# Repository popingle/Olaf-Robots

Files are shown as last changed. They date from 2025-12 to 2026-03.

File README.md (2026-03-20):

# Olaf Robotics

<p align="center">
  
  <br>
  <code>CA : 5fRBazdaTiagUCimxsdhJWZkjYxPFPcUXDG6ngFBpump </code>
</p>

**Olaf Robotics** is an open-source project dedicated to bringing an animated character to life in the physical world. Our goal is to provide a compact, scale-accurate, and highly expressive robotic platform based on the Olaf character, as detailed in the research paper *"Olaf: Bringing an Animated Character to Life in the Physical World"*.

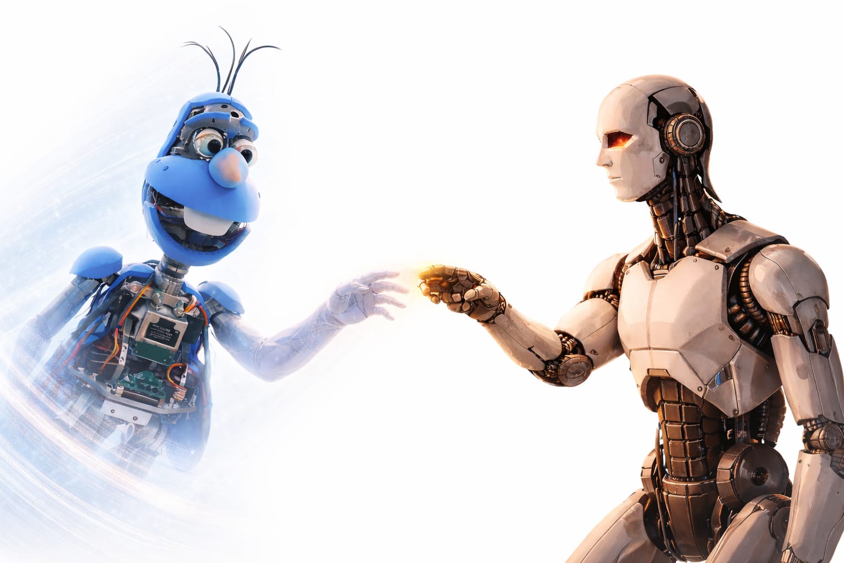
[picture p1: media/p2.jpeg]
Olaf Robotics Banner


---

## 🌐 Multilingual Documentation / 文档 / Dokumentasi

- [English](#overview)
- [Bahasa Indonesia](#ringkasan)
- [中文 (Chinese)](#项目概述)

---

## Overview

Olaf Robotics is a miniaturized, self-walking robotic character designed for agility and believability. This repository contains the mechatronic design (3D printable parts), high-fidelity simulation environments, and reinforcement learning-based control software.

<table align="center">
  <tr>
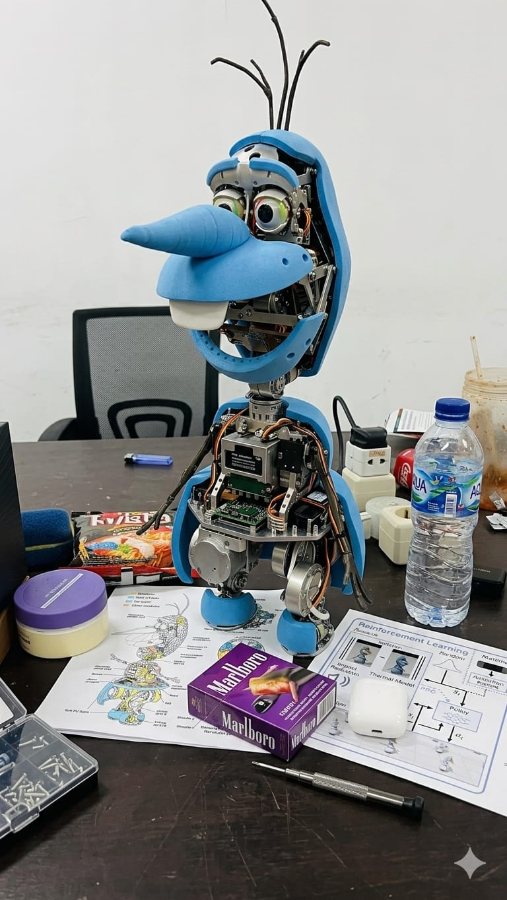
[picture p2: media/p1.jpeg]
Olaf Robot 1
    <td align="center"></td>
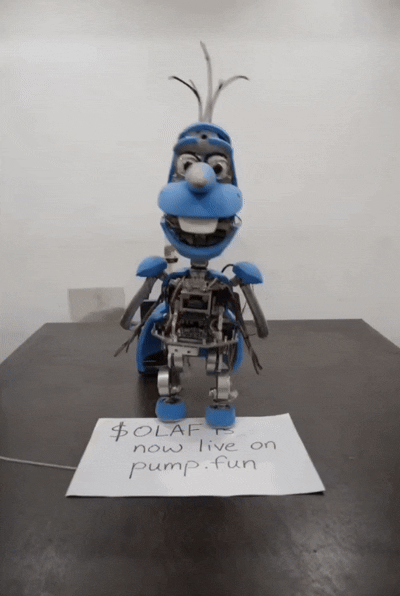
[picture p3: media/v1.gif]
Olaf Animation 1
    <td align="center"></td>
  </tr>
</table>

### 🏗️ Technical Architecture

Our architecture is built on a modular three-layer stack to ensure seamless sim-to-real transition and expressive motion:

Technical Architecture

### 🧠 Split-Brain Architecture Flow
Our dual-processor system separates locomotion from expression to ensure high-frequency motor control and rich social interaction:

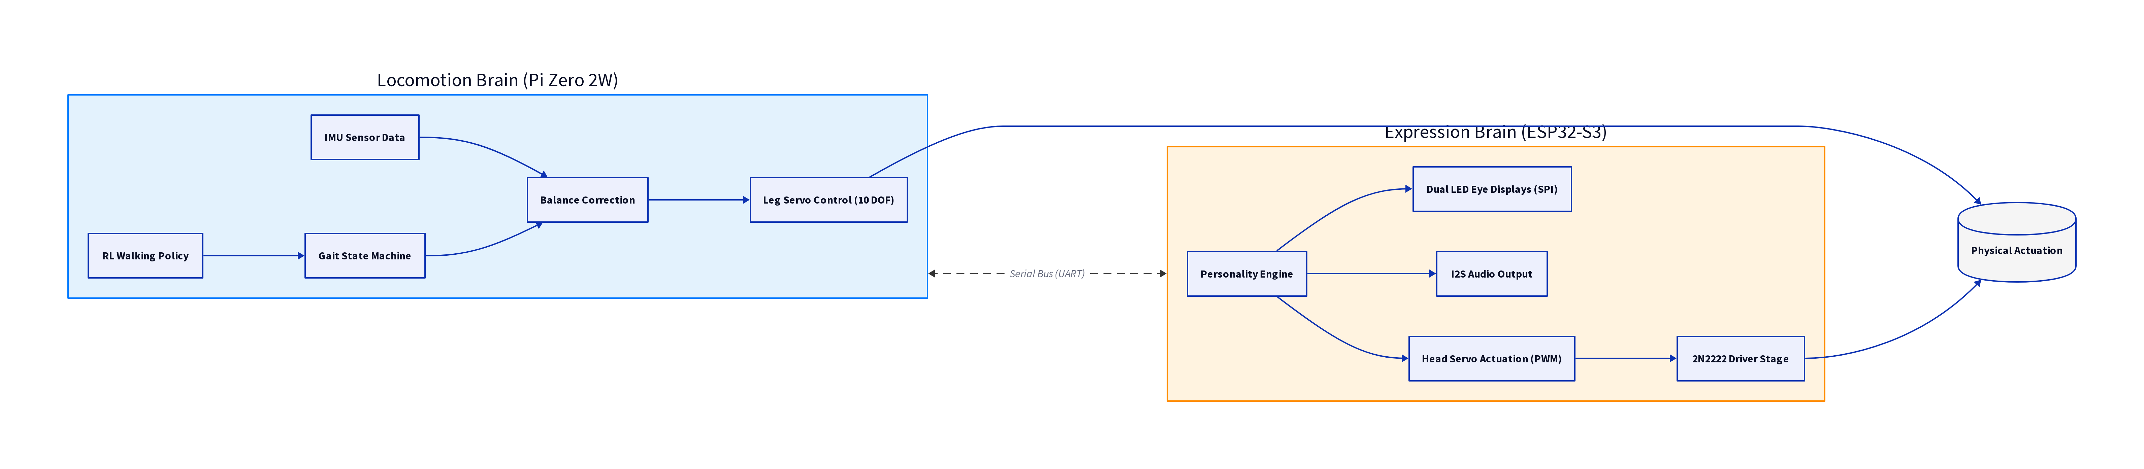
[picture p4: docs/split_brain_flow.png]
Split-Brain Architecture


### ⚙️ Mechatronic Design

The robot's internal structure is meticulously designed to balance weight, power, and expressivity. The shells and skirt are cut away in the diagram below to reveal the complex interior:

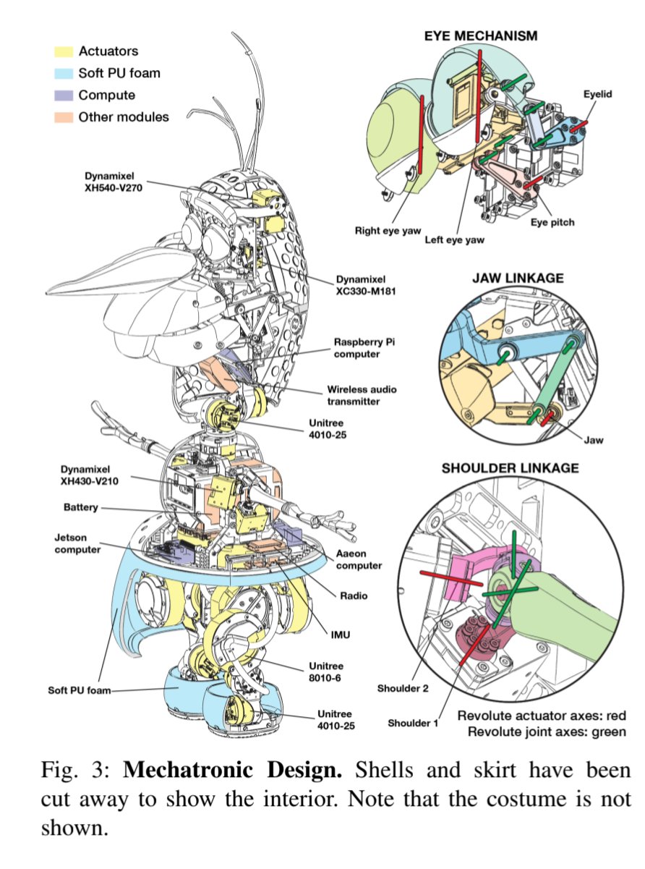
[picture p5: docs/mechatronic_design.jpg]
Mechatronic Design


#### Key Components:
- **Actuators (Yellow)**: High-performance Dynamixel (XH540, XC330, XH430) and Unitree (4010, 8010) motors.
- **Compute (Purple)**: Dual-brain system featuring a **Jetson Computer** for high-level tasks and a **Raspberry Pi** for auxiliary control.
- **Soft PU Foam (Blue)**: Lightweight exterior padding for safety and lifelike feel.
- **Specialized Mechanisms**:
    - **Eye Mechanism**: 3-DoF control for pitch and yaw (left/right) with eyelid movement.
    - **Jaw Linkage**: Precise linkage for expressive mouth movements.
    - **Shoulder Linkage**: Revolute joint axes (red/green) for fluid arm motion.

### 🤖 RL-based Control

We separate the articulated backbone from the show functions. The backbone is controlled via policies conditioned on the high-level control input `gt` and trained using a combination of imitation, overheating, and impact rewards. During training, the control inputs are randomized, whereas at runtime, the Animation Engine generates control inputs from puppeteering commands.

Mechatronic Design and RL-based Control

#### Thermal-aware Policy Performance

Our thermal-aware policy effectively prevents actuator overheating, as demonstrated by the comparison below. The policy significantly reduces joint error and torque when operating under thermal constraints.

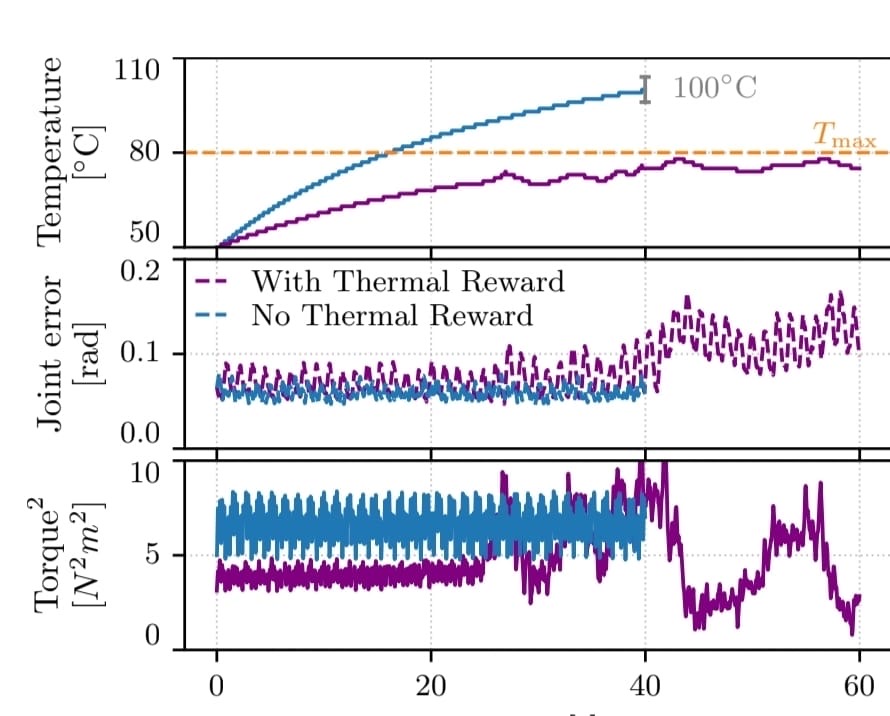
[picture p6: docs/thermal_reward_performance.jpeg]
Thermal Reward Performance


#### Impact Reduction Performance

To ensure quieter and more believable movement, our RL policies incorporate impact noise reduction rewards. The graph below illustrates how this approach minimizes impact forces during locomotion.

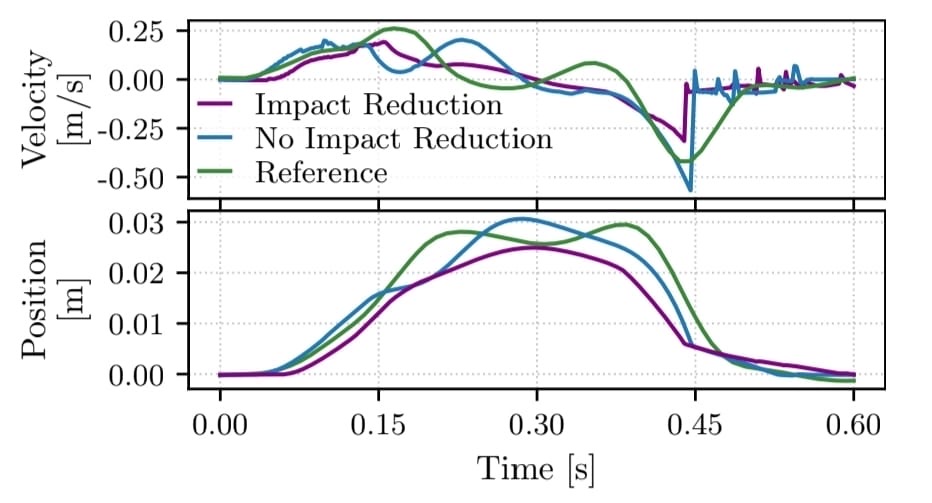
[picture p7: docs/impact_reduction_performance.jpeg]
Impact Reduction Performance


1.  **Mechatronic Design**:
    *   Novel asymmetric **six-degrees-of-freedom (6-DoF)** leg mechanism.
    *   Remotely actuated spherical, planar, and spatial linkages for arms, mouth, and eyes.
    *   Compact design fully hidden beneath a soft foam costume.
2.  **Control Layer (RL & Thermal-aware)**:
    *   **Reinforcement Learning (RL)** policies guided by animation references for lifelike motion.
    *   **Thermal-aware policy** that incorporates actuator temperature to prevent overheating in the slim neck.
    *   Impact noise reduction rewards for quieter, more believable movement.
3.  **Simulation Layer (MuJoCo)**:
    *   High-fidelity physics simulation using **MuJoCo**.
    *   Domain randomization for robust sim-to-real transfer.

### 🛠️ Advanced Features

*   **Polyglot Core Engine**: High-performance components implemented in **C++17**, **C**, and **Rust** for real-time control, low-level communication, and sensor processing.
*   **CI/CD Pipeline**: Automated build and test workflows using GitHub Actions to ensure code stability across multiple languages.
*   **Multilingual Support**: Comprehensive documentation in English, Indonesian, and Chinese.
*   **Modular Design**: Decoupled simulation and hardware layers for rapid prototyping.

---

## Ringkasan

Olaf Robotics adalah proyek robotika open-source yang bertujuan untuk menghidupkan karakter animasi di dunia nyata. Robot ini dirancang dengan fokus pada ekspresi, kelincahan, dan kemiripan dengan karakter aslinya.

### ⚙️ Desain Mekatronik

Struktur internal robot dirancang secara presisi untuk menyeimbangkan berat, daya, dan ekspresivitas. Diagram di bawah menunjukkan komponen interior tanpa kostum:

Mechatronic Design

#### Komponen Utama:
- **Aktuator (Kuning)**: Motor Dynamixel dan Unitree berperforma tinggi.
- **Komputasi (Ungu)**: Sistem dual-brain menggunakan **Jetson Computer** dan **Raspberry Pi**.
- **Mekanisme Khusus**: Kontrol mata 3-DoF, linkage rahang untuk mulut, dan linkage bahu untuk gerakan lengan yang luwes.

### 🤖 Kontrol Berbasis RL

Kami memisahkan *articulated backbone* dari fungsi pertunjukan. *Backbone* dikendalikan melalui kebijakan yang dikondisikan pada input kontrol tingkat tinggi `gt` dan dilatih menggunakan kombinasi imitasi, *overheating*, dan *impact rewards*. Selama pelatihan, input kontrol diacak, sedangkan saat runtime, *Animation Engine* menghasilkan input kontrol dari perintah *puppeteering*.

Mechatronic Design and RL-based Control

#### Performa Kebijakan Sadar Termal

Kebijakan sadar termal kami secara efektif mencegah *overheating* aktuator, seperti yang ditunjukkan oleh perbandingan di bawah ini. Kebijakan ini secara signifikan mengurangi kesalahan sendi dan torsi saat beroperasi di bawah batasan termal.

Thermal Reward Performance

#### Performa Pengurangan Dampak

Untuk memastikan gerakan yang lebih tenang dan meyakinkan, kebijakan RL kami menggabungkan *reward* pengurangan kebisingan dampak. Grafik di bawah ini mengilustrasikan bagaimana pendekatan ini meminimalkan gaya dampak selama lokomosi.

Impact Reduction Performance

1.  **Desain Mekatronik**: Mekanisme kaki 6-DoF asimetris yang inovatif dan linkage untuk lengan, mulut, dan mata.
2.  **Lapisan Kontrol**: Kebijakan Reinforcement Learning (RL) yang dipandu oleh referensi animasi dan kebijakan sadar termal untuk mencegah overheating.
3.  **Lapisan Simulasi**: Simulasi fisika fidelitas tinggi menggunakan MuJoCo.

---

## 项目概述

Olaf Robotics 是一个开源机器人项目，旨在将动画角色带入现实世界。该机器人专注于表现力、灵活性和与原角色的比例一致性。

### ⚙️ 机电设计

机器人的内部结构经过精心设计，以平衡重量、动力和表现力。下图展示了去除外壳后的内部组件：

Mechatronic Design

#### 核心组件：
- **执行器（黄色）**：高性能 Dynamixel 和 Unitree 电机。
- **计算单元（紫色）**：搭载 **Jetson** 和 **Raspberry Pi** 的双大脑系统。
- **专用机构**：3自由度眼睛机构、用于表情的下颌连杆以及用于流畅手臂动作的肩部连杆。

### 🤖 基于RL的控制

我们将关节骨架与表演功能分离。骨架通过以高级控制输入 `gt` 为条件的策略进行控制，并使用模仿、过热和冲击奖励的组合进行训练。在训练期间，控制输入是随机的，而在运行时，动画引擎从操纵命令生成控制输入。

Mechatronic Design and RL-based Control

#### 热感知策略性能

我们的热感知策略有效地防止了执行器过热，如下面的比较所示。该策略在热限制下显著降低了关节误差和扭矩。

Thermal Reward Performance

#### 冲击减少性能

为了确保更安静、更逼真的运动，我们的强化学习策略结合了冲击噪声减少奖励。下图说明了这种方法如何在运动过程中最大限度地减少冲击力。

Impact Reduction Performance

1.  **机电设计**：创新的非对称六自由度 (6-DoF) 腿部机构，以及用于手臂、嘴巴和眼睛的远程驱动连杆。
2.  **控制层**：由动画参考引导的强化学习 (RL) 策略，以及包含执行器温度输入的散热感知策略。
3.  **仿真层**：使用 MuJoCo 进行高保真物理仿真。

---

## Getting Started

### Hardware Assembly
Detailed assembly instructions can be found in the [Assembly Guide](docs/assembly_guide.md).

#### 📋 Bill of Materials (BOM)
The total cost for the Olaf Robot hardware is designed to be accessible. Below is the visual breakdown:

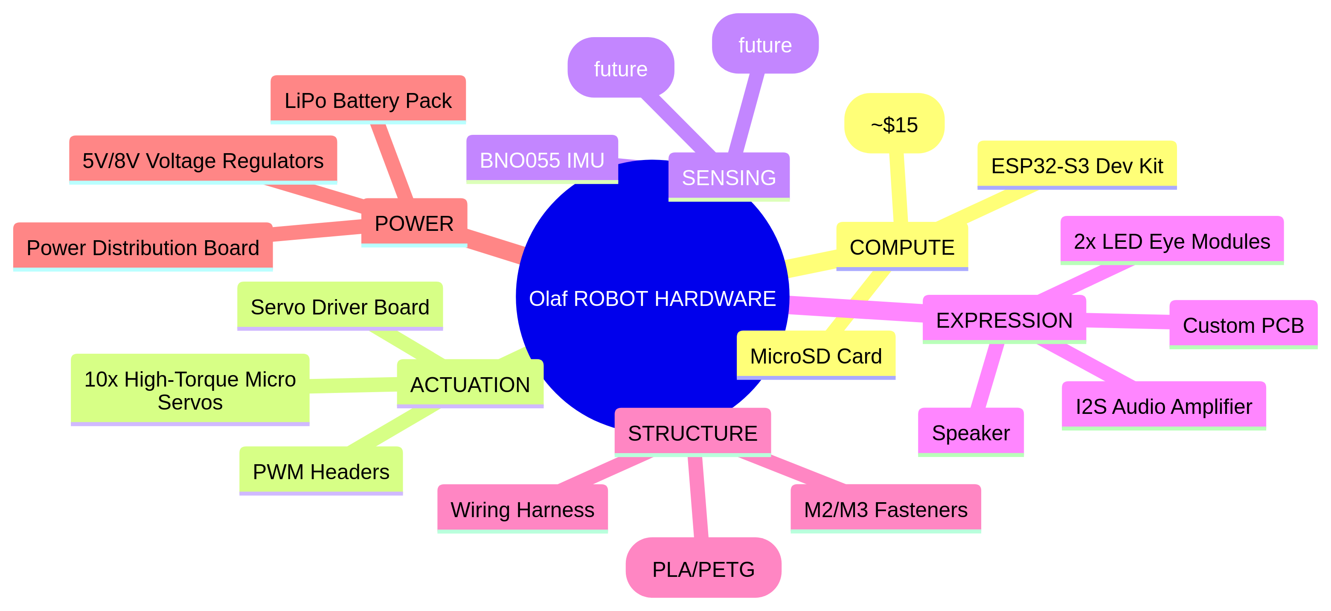
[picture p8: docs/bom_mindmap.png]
Olaf Robotics BOM Mind Map


### Software Installation
To install the core library and dependencies:
```bash
pip install -e .
```

### Simulation
We use MuJoCo for simulation. You can find the robot descriptions and simulation scripts in the `olaf_robot/robots` and `experiments` directories.

## Project Structure
- `print/`: STL files and 3D printing modifications.
- `olaf_robot/`: Core Python package and robot descriptions.
- `docs/`: Documentation and wiring diagrams.
- `experiments/`: Research scripts for RL, motion planning, and real-robot tests.
- `src/`: Polyglot core engine (C++, C, Rust).
- `scripts/`: Automation and deployment scripts.

## License
This project is licensed under the MIT License - see the [LICENSE](LICENSE) file for details.

---
*Bringing an animated character to life in the physical world.*

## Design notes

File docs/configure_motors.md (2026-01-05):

# Configure the motors

> This sould be done independently on each motor *before* builiding the Olaf.
>
> During the process, the motor will move to its zero position. You can then install the horn while trying to align it the best you can like in the photo below. (Don't worry if it's not perfect, we will compensate for that later)

Capture d’écran du 2025-04-25 09-55-34

Clone and install (`pip install -e .`) the runtime repo on the `v2` branch : `https://github.com/olaf-robotics/Olaf_Robots_Runtime`

You can either install it on your own computer or on the raspberry pi for the configuration, as you want. You'll just want a way to power the servos, for example, the battery pack.

Then for each motor, run the following command : 

```bash
python configure_motor.py --id <id>
```

The motors ids are : 

```python
{
    "left_hip_yaw": 20,
    "left_hip_roll": 21,
    "left_hip_pitch": 22,
    "left_knee": 23,
    "left_ankle": 24,
    "neck_pitch": 30,
    "head_pitch": 31,
    "head_yaw": 32,
    "head_roll": 33,
    "right_hip_yaw": 10,
    "right_hip_roll": 11,
    "right_hip_pitch": 12,
    "right_knee": 13,
    "right_ankle": 14,
}
```

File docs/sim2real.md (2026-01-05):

> Not finalized yet

# Training policies that transfer to the real robot (sim2real)

We want to train policies that transfer well to the real robot. This is the sim2real problem. It's a hard problem, especially for us since we are using cheap servomotors that are hard to model and not overly powerful. 

Below, I'll roughly explain the steps we went through to get there, but you won't have to do everything again yourself since we provide the results of each process.

## Make an accurate model of the robot (URDF/MJCF)

### Robot structure

In the [Onhape document](https://cad.onshape.com/documents/64074dfcfa379b37d8a47762/w/3650ab4221e215a4f65eb7fe/e/0505c262d882183a25049d05), we specify the material of each part. But to be more accurate, because we print with infill we override the mass of the parts with the (pretty accurate) estimation of the slicer. 

We use [onshape-to-robot](https://github.com/Rhoban/onshape-to-robot) to export URDF/MJCF descriptions. For MJX, we have to make a lightweight model, see our [config.json](https://github.com/olaf-robotics/Open_Olaf_Playground/blob/main/playground/Olaf_Robots_v2/xmls/config.json). 

This gives us a MJCF (Mujoco format) [description of the robot](https://github.com/olaf-robotics/Open_Olaf_Playground/blob/main/playground/Olaf_Robots_v2/xmls/Olaf_Robots_v2.xml) which describes the masses and moments of inertia of the full robot. 

### Motors

Another very important part of having an accurate model is modeling the motors's behavior. We use [BAM](https://github.com/Rhoban/bam/) for that. You don't have to go through the identification process yourself, we provide the results [here](https://github.com/Rhoban/bam/tree/main/params/feetech_sts3215_7_4V)

It's critical that the simulator simulates the motors accurately, because we will train a policy (a neural network) to output motor positions based on sensory inputs (motors positions/speeds, imu and feet sensors). If the motors behave differently in the simulation than in the real world, the policy won't work, or at worst, produce chaotic movements.

`BAM` allows us to export the main identified parameters to mujoco units (using `bam.to_mujoco`). These values are the ones we set in out mjcf model for the actuators and joints properties. 

- damping
- kp
- frictionloss
- armature
- forcerange

## Training policies 

We use our own [mujoco playground](https://github.com/google-deepmind/mujoco_playground) based framework, [Open Olaf Playground](https://github.com/olaf-robotics/Open_Olaf_Playground)

In the [joystick](https://github.com/olaf-robotics/Open_Olaf_Playground/blob/main/playground/Olaf_Robots_v2/joystick.py) env, you can try to enable/disable different rewards, write your own, play with the weights, noise, randomization etc. 

We obtained good results by implementing the imitation reward described by Disney in their [Olaf paper](https://github.com/olaf-robotics/Open_Olaf_Playground/blob/main/playground/Olaf_Robots_v2/joystick.py). 

To use this reward, we need reference motion. We made [this repo](https://github.com/olaf-robotics/Open_Olaf_reference_motion_generator) to generate such motion using a parametric walk engine. Following the instructions there, you can generate a `polynomial_coefficients.pkl` file which contains the reference motions. There is already such a file in the playground repo under the `data/` directory. 

Once your policy is trained, you can try to run it on the real robot using [this script](https://github.com/olaf-robotics/Olaf_Robots_Runtime/blob/v2/scripts/v2_rl_walk_mujoco.py) in the runtime repo. Make sure you completed all the steps in the [checklist](https://github.com/olaf-robotics/Olaf_Robots_Runtime/blob/v2/checklist.md) before running this.

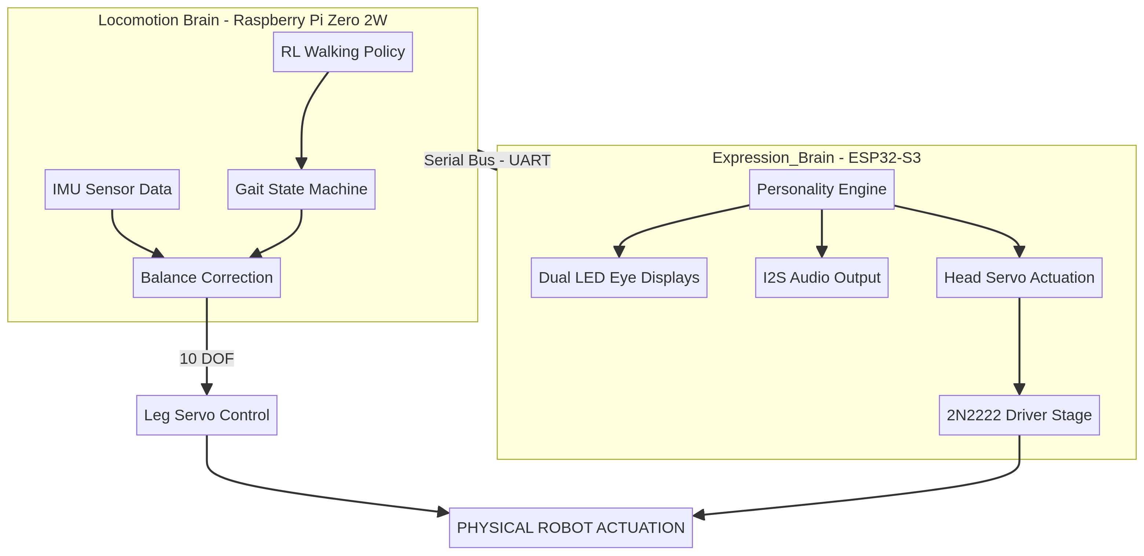
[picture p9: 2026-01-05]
docs/split_brain_architecture.png

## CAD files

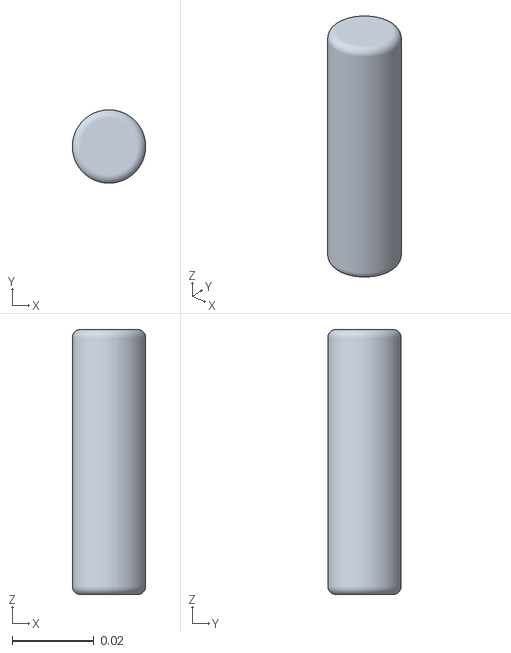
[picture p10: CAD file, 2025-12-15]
olaf_robot/robots/bdx/cell.stl
0.018 x 0.018 x 0.065

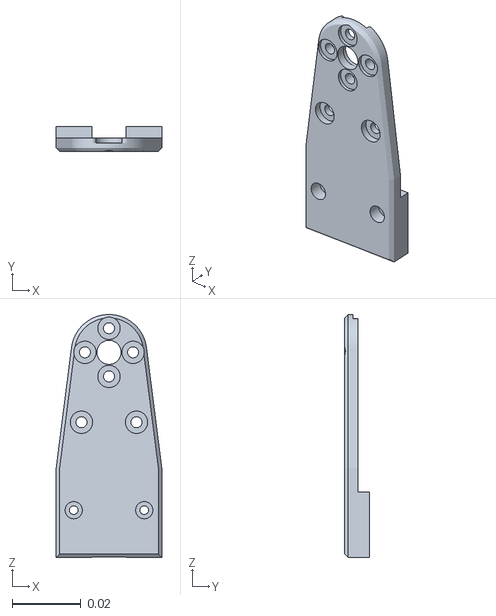
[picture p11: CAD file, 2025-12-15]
olaf_robot/robots/olaf_robots_v2/left_knee_to_ankle_right_sheet.stl
0.0307 x 0.0072 x 0.0706

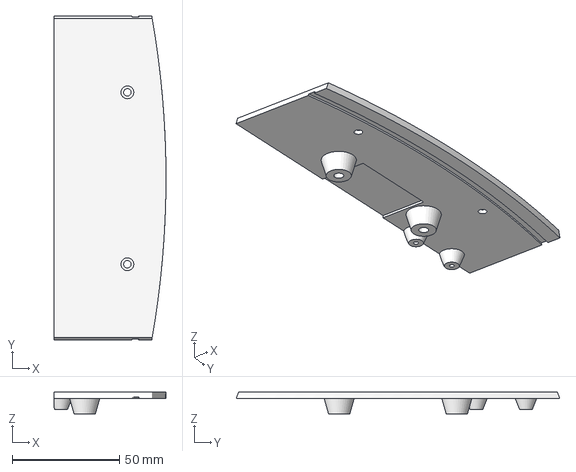
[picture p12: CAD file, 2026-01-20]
print/mods/Justins_Park_Head_Mod/print cut for A1/Front_Top.3mf
52.1 x 150.6 x 10.1 mm

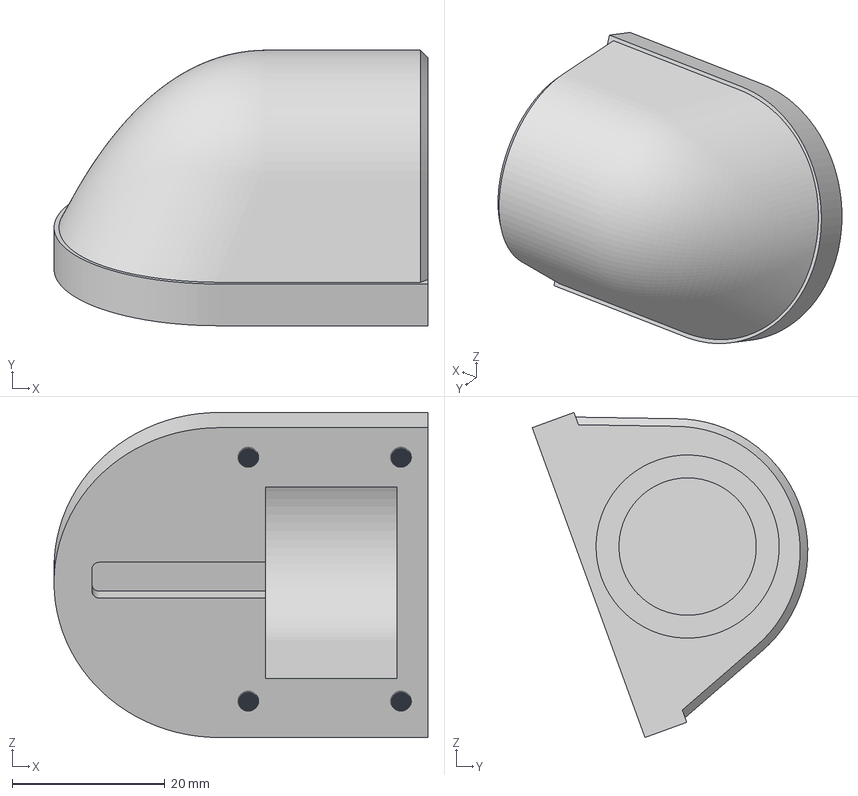
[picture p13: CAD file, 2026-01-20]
print/mods/Justins_Park_Head_Mod/print/FlashlightBody.3mf
49.0 x 36.1 x 42.6 mm

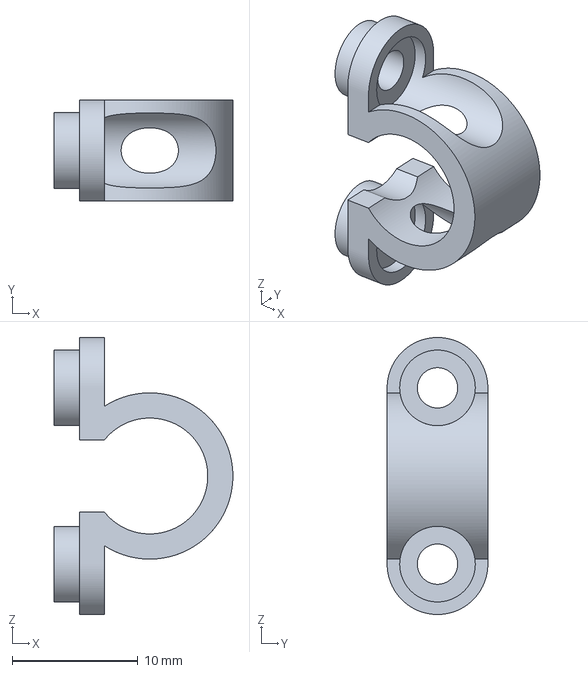
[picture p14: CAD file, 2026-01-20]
print/mods/v2_Jaimes_Mods/Hip Cable Holder.3mf
14.2 x 8.00 x 22.0 mm

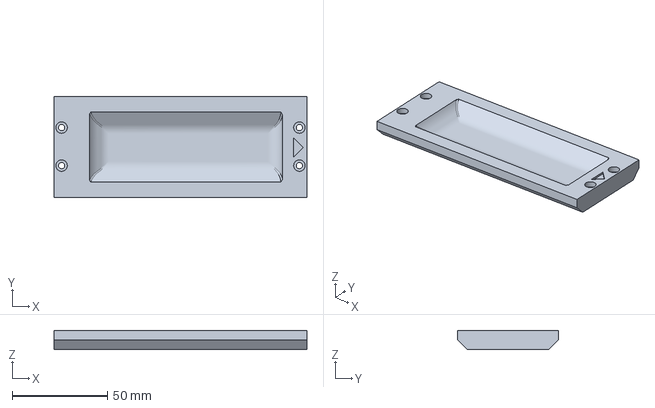
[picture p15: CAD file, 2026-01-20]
print/mods/v2_Jaimes_Mods/stand/Left_foot_pad.3mf
133.0 x 52.8 x 10.1 mm

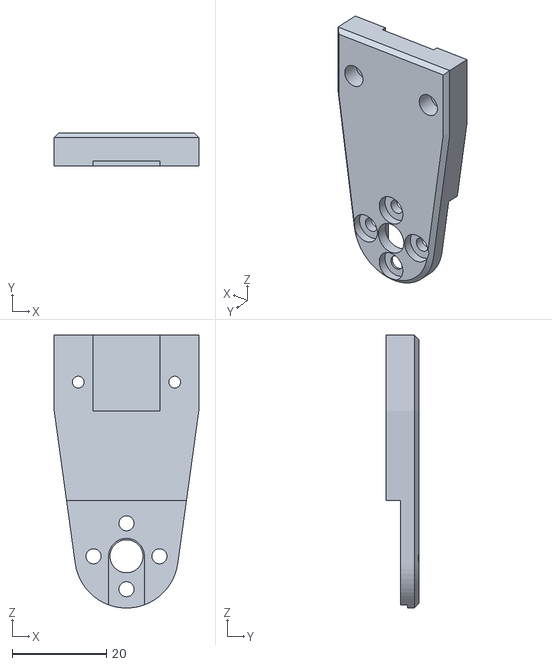
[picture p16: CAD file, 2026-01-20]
print/neck_left_sheet.stl
30.7 x 7.05 x 58.0

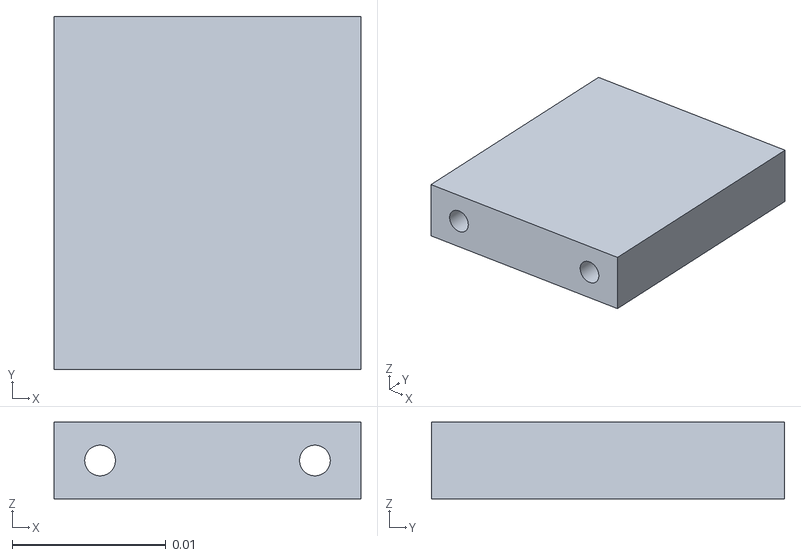
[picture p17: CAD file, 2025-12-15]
olaf_robot/robots/bdx/renfort_leg.stl
0.02 x 0.023 x 0.005

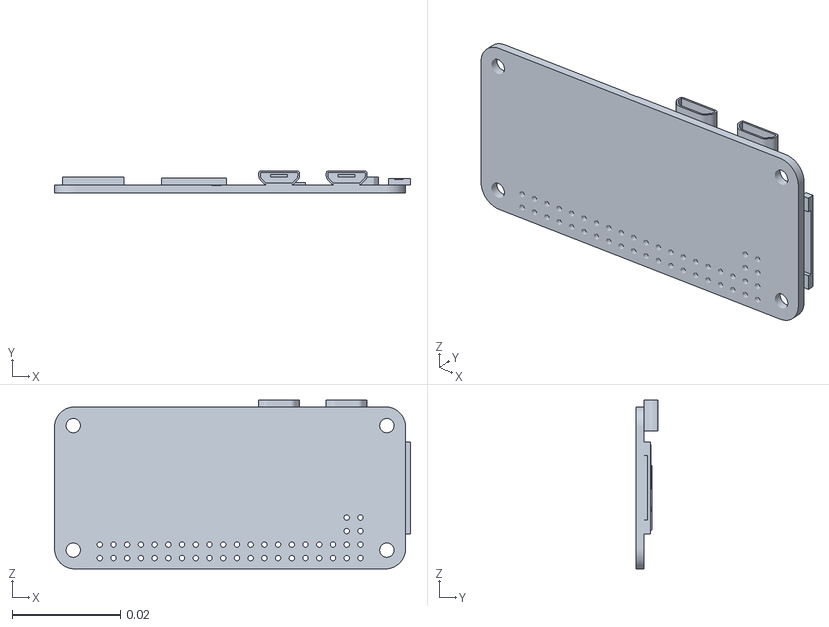
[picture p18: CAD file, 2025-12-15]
olaf_robot/robots/olaf_robots_v2/raspberrypizerow.stl
0.0659 x 0.0041 x 0.0312

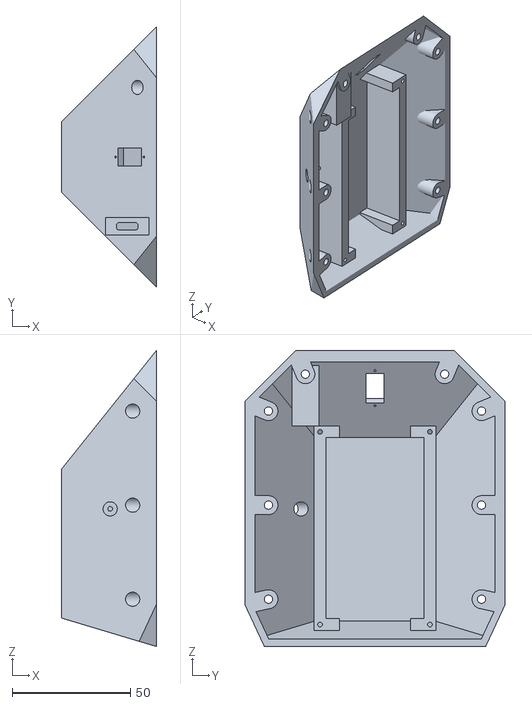
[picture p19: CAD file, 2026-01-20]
print/body_back.stl
40.0 x 110.0 x 125.0

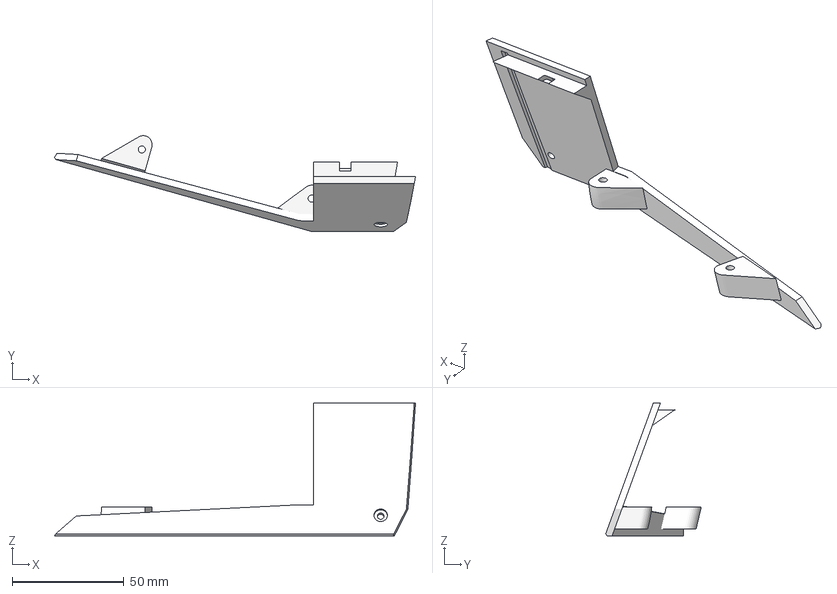
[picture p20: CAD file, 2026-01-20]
print/mods/Justins_Park_Head_Mod/print cut for A1/Front_Right.3mf
161.4 x 42.8 x 59.4 mm

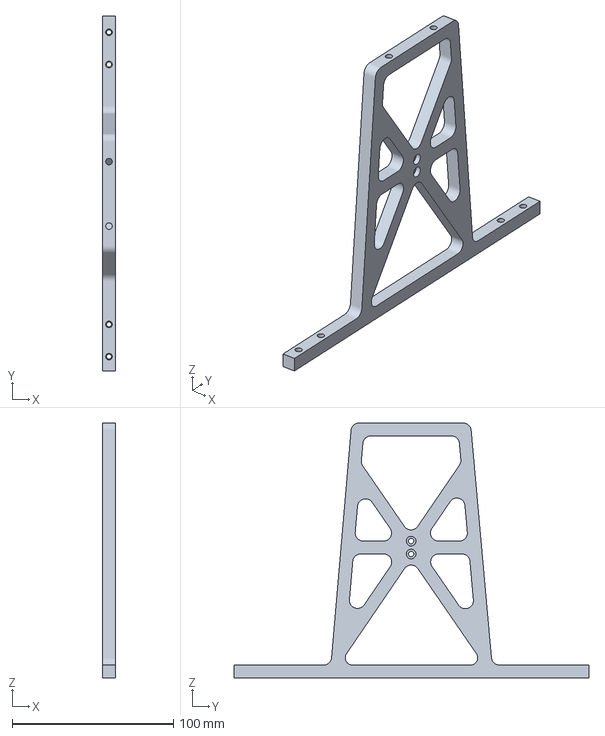
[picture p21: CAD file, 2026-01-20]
print/mods/v2_Jaimes_Mods/stand/stand_front.3mf
8.00 x 220.0 x 158.2 mm

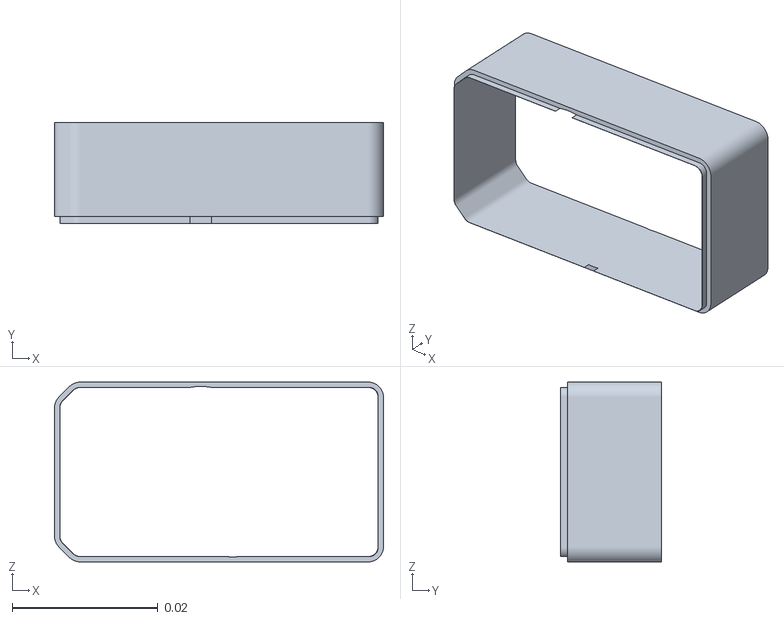
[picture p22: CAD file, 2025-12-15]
olaf_robot/robots/olaf_robots_v2/wj-wk00-0123middlecase_56.stl
0.0452 x 0.0139 x 0.0247

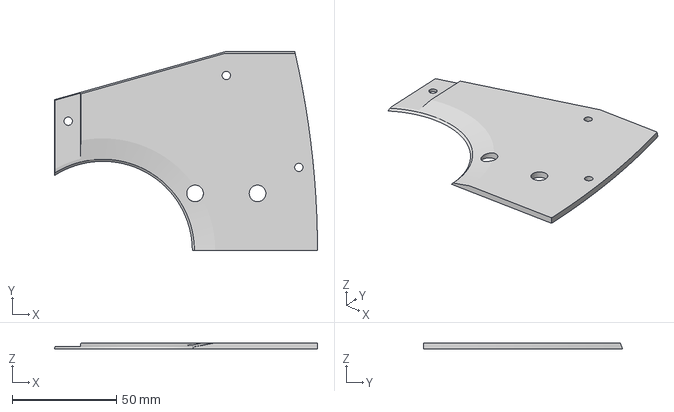
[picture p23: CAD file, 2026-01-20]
print/mods/Justins_Park_Head_Mod/print cut for A1/Base_FrontLeft.3mf
126.3 x 95.7 x 3.00 mm

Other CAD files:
print/mods/Justins_Park_Head_Mod/print/Parklike_Left_Eye.3mf
print/mods/v2_Jaimes_Mods/Bambu_X1C_Project_File.3mf
print/mods/Justins_Park_Head_Mod/print/Parklike_Right_Eye.3mf
print/mods/v2_Jaimes_Mods/stand/Right_foot_pad.3mf
olaf_robot/robots/bdx/39281023.prt.stl
olaf_robot/robots/bdx/antenna.stl
olaf_robot/robots/bdx/antenna_holder_left.stl
olaf_robot/robots/bdx/antenna_holder_right.stl
olaf_robot/robots/bdx/antenna_motor_holder.stl
olaf_robot/robots/bdx/antenna_tip.stl
olaf_robot/robots/bdx/axis_to_axis.stl
olaf_robot/robots/bdx/block_to_axis.stl
olaf_robot/robots/bdx/bms.stl
olaf_robot/robots/bdx/bno055.stl
olaf_robot/robots/bdx/board.stl
olaf_robot/robots/bdx/body_part.stl
olaf_robot/robots/bdx/cage_back.stl
olaf_robot/robots/bdx/cage_bottom.stl
olaf_robot/robots/bdx/cage_bottom_battery_hold.stl
olaf_robot/robots/bdx/cage_top.stl
olaf_robot/robots/bdx/dc15_a01_case_b_dummy.stl
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

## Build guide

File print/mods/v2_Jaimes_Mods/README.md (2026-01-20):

# Jaime's V2 BD‑X Style Body Covers Mod

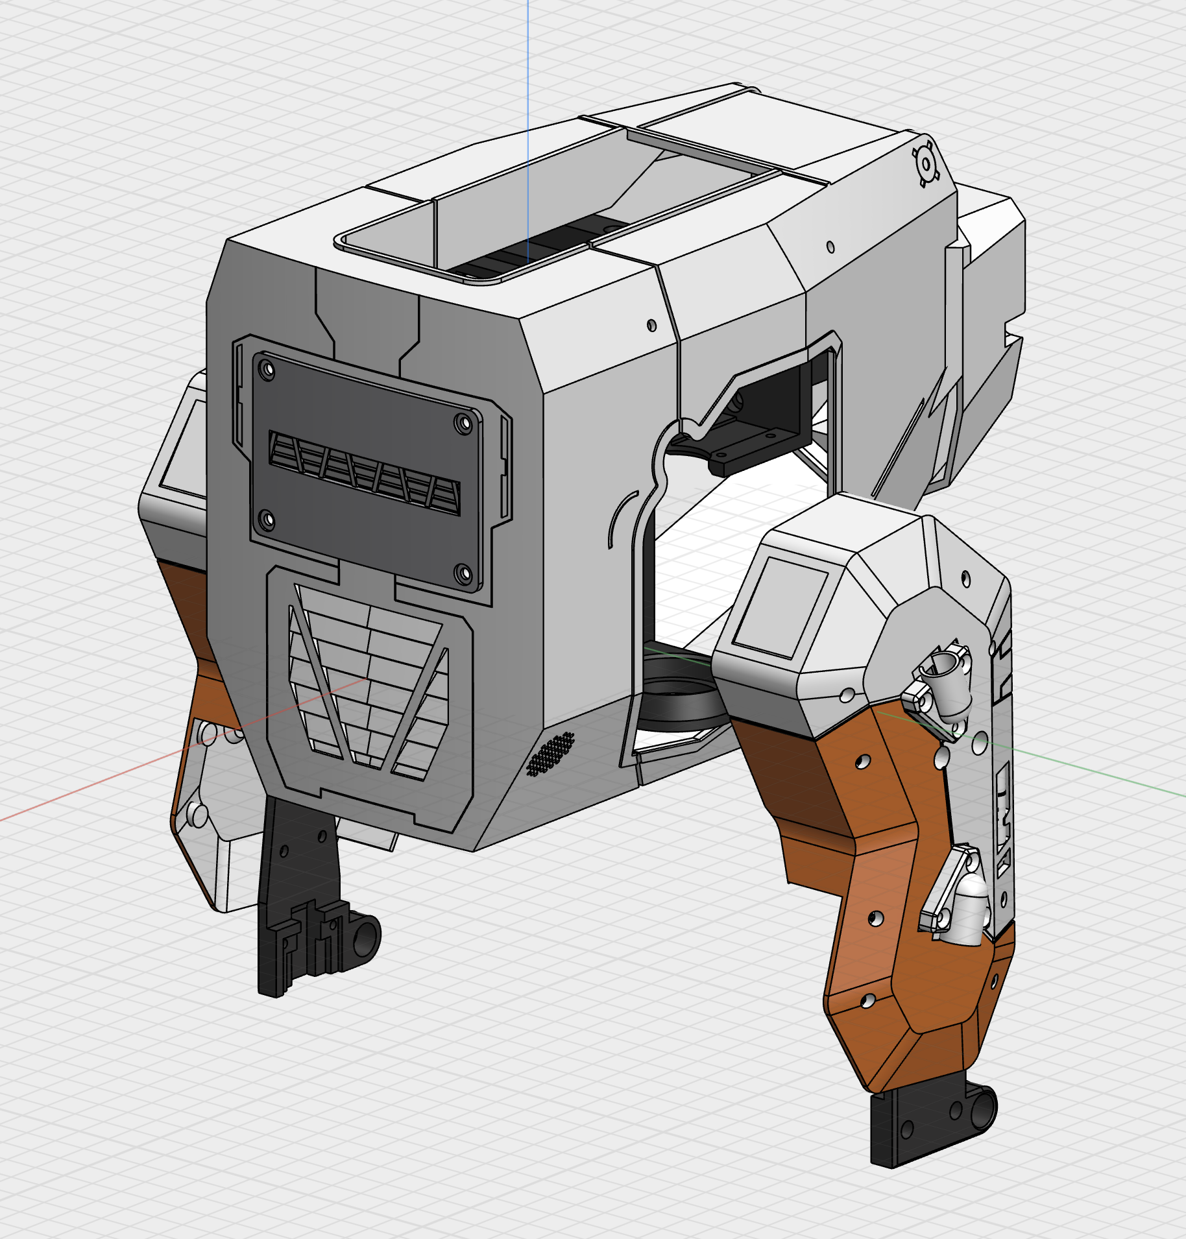
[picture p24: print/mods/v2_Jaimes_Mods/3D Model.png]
3D Model Overview


Author: Jaime Machuca (jmachuca77)

## Purpose
This is an alternative set of v2 body/head cover parts for Olaf Robots intended to more closely match the Disney BD‑X aesthetic and surface "skin" lines.

## Important Note on Balance & RL Policy
These covers shift the overall mass distribution and do not perfectly match the original center of gravity assumptions used when training the current reinforcement learning (RL) locomotion policy. The existing policy still works, but may exhibit slightly reduced stability (e.g. more wobble, occasional recovery steps). Monitor performance; if instability becomes an issue, consider fine‑tuning or retraining with updated inertial parameters.

## Printing Guidance
The file `Bambu_X1C_Project_File.3mf` contains suggested part orientations, plate groupings, and baseline settings optimized for a Bambu Labs X1C printer.

Recommended starting points (adjust to your material):
- Material: PETG or PLA-CF (for durability)
- Layer Height: 0.20 mm (features) / 0.28 mm (large flat shells optional)
- Infill: 15–20% gyroid or cubic
- Walls: 3 perimeters for strength on structural covers
- Supports: Only where unavoidable (check project file flags)
- Adhesion: Skirt or minimal brim for tall narrow pieces

Print Orientation Reference

## Included Parts
Representative filenames (see folder for full list):
- Front/Back/Side body covers (`Front Cover.3mf`, `Back Panel.3mf`, `trunk_*`) 
- Leg covers and cable guides (`Left Leg Cover.3mf`, `Right Leg Cover.3mf`, upper/lower guides) 
- Greebles & panels (`Front Greeble.3mf`, `Front Panel V4.3mf`) 
- Safety / accessory plates (`E-Stop Panel.3mf`, `E-Stop Adapter Plate.3mf`) 
- Assembly helpers (`Hip Cable Holder.3mf`, `Top Body Support.3mf`)

## Usage & Attribution
Feel free to remix or adapt. Please retain attribution to Jaime Machuca (jmachuca77) and reference that this mod targets a closer Disney BD‑X visual style.

## Future Suggestions
- Retrain or fine‑tune RL policy with updated CAD mass properties.

---
If you encounter issues or improved orientations, open a PR or add notes here.

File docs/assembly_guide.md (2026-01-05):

# Assembly guide

> Before assembling the Olaf, you should first [configure your motors](./configure_motors.md)

## Requirements : 

You will need : 
- A soldering iron, and basic electronics tools and skills
- X m3 screws (TODO : add the exact number)
- Some wire
- Loctite Threadlocker blue 243

> General note : Everytime you screw something in the motors metal against metal, you want to use a little loctite threadlocker. This will prevent the screws from coming loose due to the vibrations during the operation of the robot. It adds a little time to to the build, but you'll be glad you took the time ;)
>
> Don't use loctite with the plastic screws

> At any time, you can refer to the CAD here : https://cad.onshape.com/documents/64074dfcfa379b37d8a47762/w/3650ab4221e215a4f65eb7fe/e/0505c262d882183a25049d05

## Steps :

### Assemble the trunk

Place the bearings in `trunk_bottom` like so, and insert M3 inserts in these holes. It's also a good time to insert the 4 M3 inserts in the bottom of this part to mount body parts later on.



Then assamble `trunk_bottom` and `trunk_top`, and screw them together with 2 `M3x10` screws through these holes



Mount the middle motor like so and screw it with the plastic screws that came with the motors : 



Insert `roll_motor_bottom` like this 



### Assemble the feet

Both feet are the same. 

First, assemble `foot_bottom_tpu` with `foot_bottom_pla`. Insert M3 inserts in these holes :



And screw the two parts together with two `M3x6` screws.

Then, insert M3 inserts in these holes in `foot_top` here : 



And assemble everything like so. Make sure the driver side of the motor is on the `foot_top` part side : 

<table>
  <tr>
    <td>  </td>
    <td>  </td>
   </tr> 
</table>

You can add the foot switches like this too :

> You press fit them so that the switch is activated when the foot touches the ground

<table>
  <tr>
    <td>  </td>
    <td>  </td>
   </tr> 
</table>

### Assemble the shins

Insert M3 Inserts in these holes of `leg_spacer` (on both sides. Insert 4 M3 inserts in total) :



Then, first plug the motor cable in the foot's motor, and make it go through the `right_sheet` like so 



Then assemble like below:



### Assemble the thighs 

The thigh is pretty much the same thing, except the `hip_pitch` motor is mounted this way (important for the zero position)



### Assemble the hips

Mount `left_roll_to_pitch` or `right_roll_to_pitch`, here the parts are symmetrical so you have to use the right one.



Mount `roll_motor_top` to the `hip_yaw` servo (screw from the bottom). Don't mount the servo to the trunk yet.



Then mount `hip_roll` like this 



And insert the sub assembly like this 



Screw everything you can (with the plastic screws provided with the servos)

You can now mount the leg like this :



And do the same for the other leg :)

Your Olaf should now look like this 



### Assemble the neck

You know the drill



### Assemble the head mechanism

First, mount `head_pitch_to_yaw` like this 



Then, independently mount `head_yaw_to_roll` and `head_roll_mount` to `head_roll dof`



(You can insert `head_bot_plate` and `body_middle_top` now too to avoid having to disassamble the head later)

Then 



Then 



Your Olaf should now look like this 



### Mount the servo driver board

TODO take a photo

### Mount the IMU

Like this 

> It's actually better to mount the IMU with the correct natural orientation, which would be flipped along the X axis compared to the pictures below
> In the picture below, the IMU is mounted upside down.
> It probably doesn't really matter a lot if you mount it upside down or not. You can configure how you mounted it later

<table>
  <tr>
    <td> </td>
    <td> </td>
   </tr> 
</table>

## Electronics

Here is the global electonics schematic for reference 

<table>
  <tr>
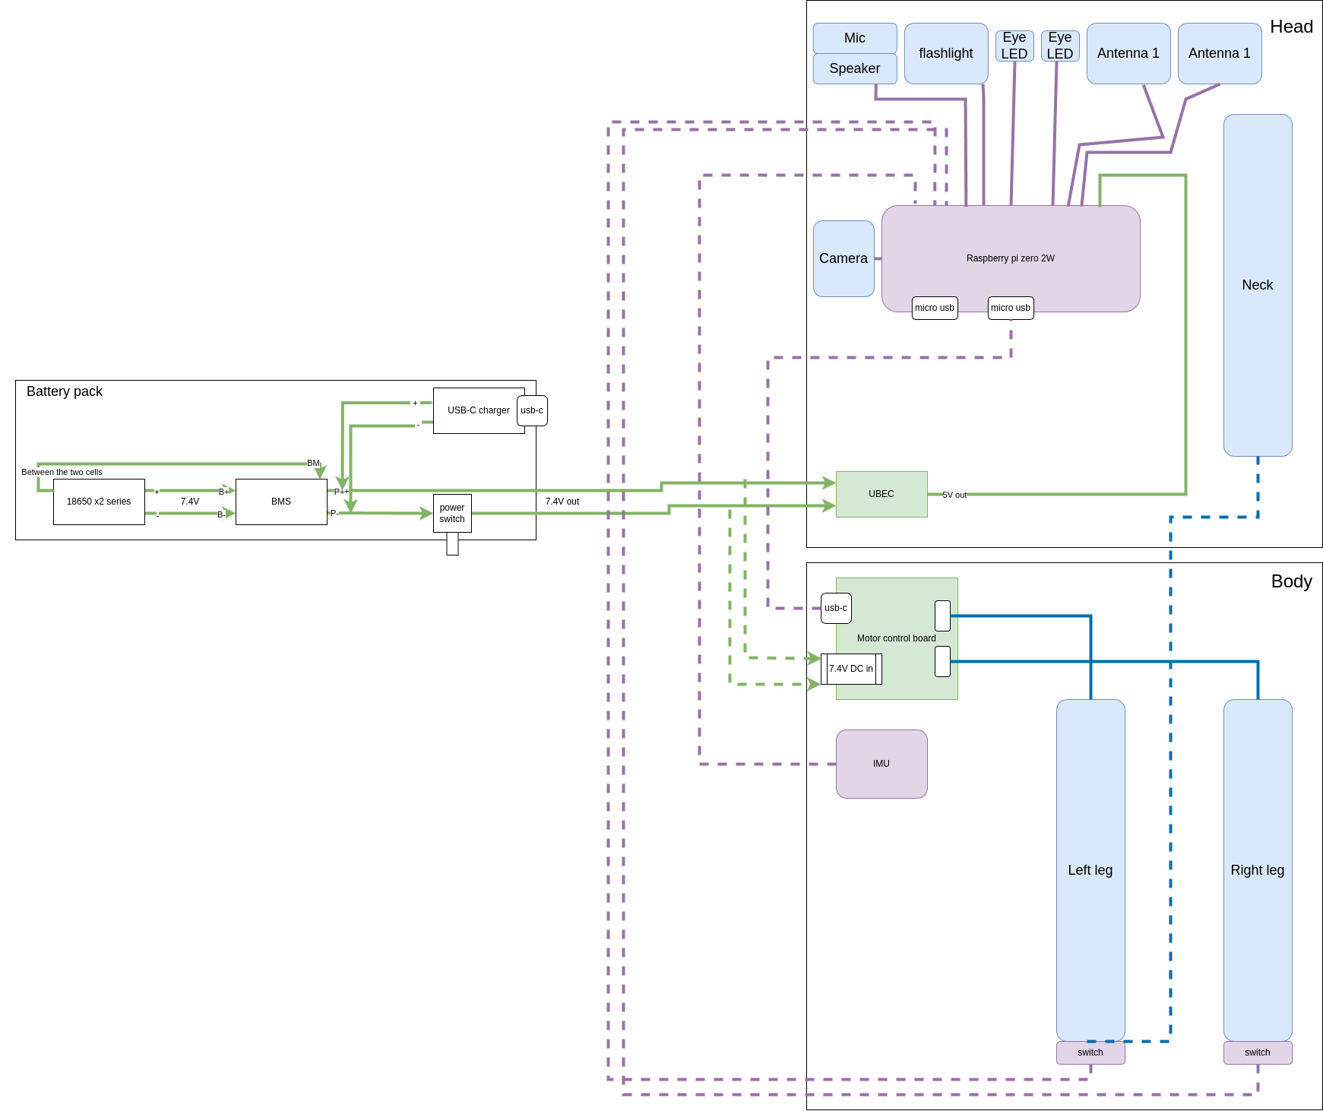
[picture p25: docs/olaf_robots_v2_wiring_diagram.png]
    <td> </td>
    <td> </td>
   </tr> 
</table>

Here is how to wire the feet 

feet

Here is the pin mapping on the Pi Zero header

| **LEDs** | **Pi Zero Header Pin** | **Pi Zero Function** |
|:---:|:---:|:---:|
|  Left Eye Anode (+) | 16 | GPIO 23 |
| Right Eye Anode (+) | 18 | GPIO 24 |
| Projector Anode (+) | 22 | GPIO 25 |
|  Common Cathode (-) | 6 | GND |
| | | |
| **Antennas** | | |
| Left PWM | 32 | GPIO 12 (PWM) |
| Right PWM | 33 | GPIO 13 (PWM) |
| 5V | 2 | 5V |
| GND | 6 | GND |
| | | |
|  **Foot Switches**  | | |
| Left Foot | 15 | GPIO 22 |
| Right Foot | 13 | GPIO 27 |
| GND | 9 | GND |
| | | |
| **BNO055** | | |
| VIN | 1 | 3V3 |
| 3VO | NC | - |
| GND | 9 | GND |
| SDA | 3 | GPIO 2 |
| SCL | 5 | GPIO 3 |
| RST | NC | - |
| | | |
| **MAX98357A** | | |
| LRC | 35 | GPIO 19 |
| BCLK | 12 | GPIO 18 |
| DIN | 40 | GPIO 21 |
| GAIN | NC | - |
| SD | NC | - |
| GND | 6 | GND |
| VIN | 2 | 5V |

### Battery pack

> To be safe, make sure your cells are charged to the same voltage before placing them in the holder.

<table>
  <tr>
    <td> </td>
    <td> </td>
   </tr> 
</table>

### Head

First, insert the M3 inserts in all these holes 



> TODO add instructions for expression features (camera, antennas, eye leds, projector and speaker)

Then insert the bearing, mount the ear motors and the raspberry pi zero 2w.

For reference, the inside of the head looks like this now 



Then assemble the neck with the head like this



## Body

First screw on `body_middle_bottom`

Capture d’écran du 2025-02-09 12-10-00

Then insert the M3 inserts in all the holes of `body_middle_bottom` and `body_middle_top` on which we'll mount the battery pack and `body_front`.

Then mount `body_middle_top`, `body_front` and the battery pack

<table>
  <tr>
    <td> </td>
    <td> </td>
   </tr> 
</table>

Et voila :) 

<table>
  <tr>
    <td> </td>
    <td> </td>
   </tr> 
</table>

> Now that your Olaf is fully assembled, you setup the raspberry pi and the runtime software [here](https://github.com/olaf-robotics/Olaf_Robots_Runtime)

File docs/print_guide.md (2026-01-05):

# Print guide

You can find the `.stl` files under the `print/` directory at the root of this repo. 

All the parts are printed in standard PLA with 15% infill, except for `foot_bottom_tpu.stl`, which is to be printed in TPU at 40% infill.

## Parts to print
- foot_top.stl x2
- foot_side.stl x2
- foot_bottom_pla.stl x2
- foot_bottom_tpu.stl x2 (TPU)
- knee_to_ankle_left_sheet.stl x4
- knee_to_ankle_right_sheet.stl x4
- leg_spacer.stl x4
- left_roll_to_pitch.stl x1
- right_roll_to_pitch.stl x1
- roll_motor_bottom.stl x2
- roll_motor_top.stl x2
- trunk_bottom.stl x1
- trunk_top.stl x1
- neck_left_sheet.stl x1
- neck_right_sheet.stl x1
- head_pitch_to_yaw.stl x1
- head_yaw_to_roll.stl x1
- head_roll_mount.stl x1
- head.stl x1
- head_bot_sheet.stl x1
- left_antenna_holder.stl x1
- right_antenna_holder.stl x1
- left_cache.stl x1
- right_cache.stl x1
- body_front.stl x1
- body_middle_bottom.stl x1
- body_middle_top.stl x1
- body_back.stl x1
- battery_pack_lid.stl x1
- bulb.stl x1
- flash_light_module.stl x1
- flash_reflector_interface.stl x1
- left_eye.stl x1
- right_eye.stl x1
- speaker_interface.stl x1
- speaker_stand.stl x1

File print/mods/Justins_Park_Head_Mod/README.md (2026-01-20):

# Justin's Park Head Mod (BD‑X Style)

This mod updates the Olaf Robots v2 head to more closely resemble the Disney BD‑X design.

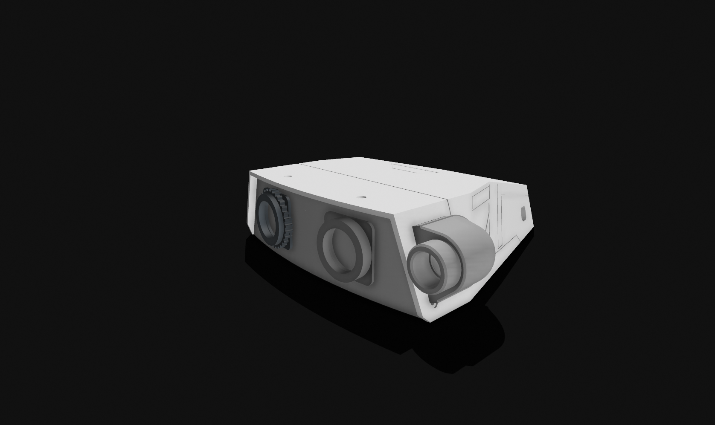
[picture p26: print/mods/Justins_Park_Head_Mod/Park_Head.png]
Park Head Mod Preview


- Author: Justin Andrews (Codezombie23)
- Project: Olaf Robots v2 head mod

If you use or remix this, please credit the author above.

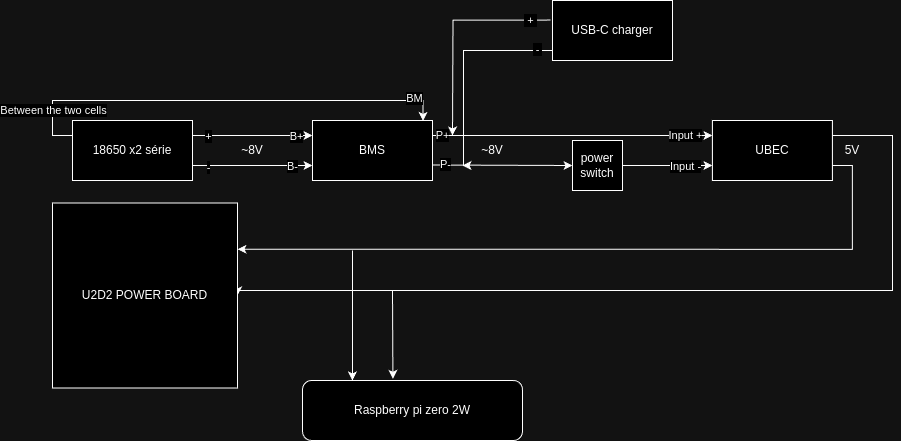
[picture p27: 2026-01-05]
docs/olaf_robots_v1_wiring_diagram.png

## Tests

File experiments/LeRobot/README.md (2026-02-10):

# Current state of things

Tried to clean up `record_episodes_hdf5.py` by using `Olaf_mujoco_server.py` but got weird behavior with the walk engine.

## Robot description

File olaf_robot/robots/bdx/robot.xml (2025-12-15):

<mujoco model="Olaf">
  <compiler angle="radian"/>
  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
  <default>
    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

    <joint damping="0.095" frictionloss="0.058" armature="0.0018"/>
    <position kp="2.54" kv="0.0" forcerange="-0.8 0.8"/>
    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

  </default>
  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
  <worldbody>
    <body name="base" pos="0 0 0.17">
    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
      <freejoint />
      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
      <body name="body_module">
        <inertial pos="-0.0067568 -0.00663747 0.00787052" quat="0.424416 0.567509 0.572577 0.412263" mass="0.501861" diaginertia="0.00136049 0.00104215 0.000854271"/>
        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
        <body name="trunk" pos="0.0325271 -0.0066039 0.0125789" quat="1 0 0 0">
          <inertial pos="0 0 0" mass="1e-09" diaginertia="0 0 0"/>
        </body>
        <body name="double_u_module" pos="0.0001271 -0.0316039 0.0230789" quat="0 0.707107 0.707107 0">
          <inertial pos="-0.017 -8.42485e-05 0.0115845" quat="0.259261 0.625097 0.282096 0.680043" mass="0.0188183" diaginertia="4.61959e-06 4.61664e-06 4.1639e-06"/>
          <joint name="right_hip_yaw" pos="0 0 0" axis="0 0 1" range="-0.698132 0.698132" />
          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
          <body name="right_hip_pitch_roll_module" pos="-0.034 0.0115 0.0115" quat="0.5 -0.5 -0.5 -0.5">
            <inertial pos="0.0119128 -0.0117521 -0.00645034" quat="0.664115 0.369051 0.335976 0.556662" mass="0.0506858" diaginertia="1.56781e-05 1.47443e-05 8.52074e-06"/>
            <joint name="right_hip_roll" pos="0 0 0" axis="0 0 1" range="-1.5708 0.436332" />
            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
            <body name="leg_module" pos="0.025 -0.0245 -0.0135" quat="0 0 -0.707107 -0.707107">
              <inertial pos="-0.0399016 -7.71133e-06 0.0114004" quat="0.502878 0.497012 0.497197 0.50288" mass="0.0345308" diaginertia="2.06535e-05 1.77761e-05 5.01407e-06"/>
              <joint name="right_hip_pitch" pos="0 0 0" axis="0 0 1" range="-0.523599 1.5708" />
              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
              <body name="leg_module_2" pos="-0.065 0 0" quat="1 0 0 0">
                <inertial pos="-0.0399016 -7.71133e-06 0.0114004" quat="0.502878 0.497012 0.497197 0.50288" mass="0.0345308" diaginertia="2.06535e-05 1.77761e-05 5.01407e-06"/>
                <joint name="right_knee" pos="0 0 0" axis="0 0 1" range="-2.0944 2.0944" />
                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
                <body name="foot_module" pos="-0.065 0 0" quat="1 0 0 0">
                  <inertial pos="-0.0268732 0.00760284 0.0115562" quat="0.443056 0.532696 -0.463707 0.552189" mass="0.0282341" diaginertia="1.31872e-05 1.21932e-05 5.15725e-06"/>
                  <joint name="right_ankle" pos="0 0 0" axis="0 0 1" range="-1.5708 1.5708" />
                  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
                  <body name="right_foot" pos="-0.0375 0 0.0115" quat="0.5 0.5 0.5 0.5">
                    <inertial pos="0 0 0" mass="1e-09" diaginertia="0 0 0"/>
                  </body>
                </body>
              </body>
            </body>
          </body>
        </body>
        <body name="double_u_module_2" pos="0.0001271 0.0183961 0.0230789" quat="0 0.707107 0.707107 0">
          <inertial pos="0.017 8.45125e-05 0.0115842" quat="-0.281391 0.680335 -0.258685 0.625336" mass="0.0188183" diaginertia="4.61959e-06 4.61664e-06 4.1639e-06"/>
          <joint name="left_hip_yaw" pos="0 0 0" axis="0 0 1" range="-0.698132 0.698132" />
          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
          <body name="left_hip_pitch_roll_module" pos="0.034 -0.0115 0.0115" quat="0.5 0.5 -0.5 0.5">
            <inertial pos="0.011923 -0.0116065 -0.0163151" quat="0.367078 0.649645 0.581274 0.324555" mass="0.0509361" diaginertia="1.57911e-05 1.48967e-05 8.554e-06"/>
            <joint name="left_hip_roll" pos="0 0 0" axis="0 0 1" range="-1.5708 0.436332" />
            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
            <body name="leg_module_3" pos="0.025 -0.0015 -0.0095" quat="2.76505e-08 2.76505e-08 0.707107 -0.707107">
              <inertial pos="-0.0399016 -7.71133e-06 0.0114004" quat="0.502878 0.497012 0.497197 0.50288" mass="0.0345308" diaginertia="2.06535e-05 1.77761e-05 5.01407e-06"/>
              <joint name="left_hip_pitch" pos="0 0 0" axis="0 0 1" range="-0.523599 1.5708" />
              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
              <body name="leg_module_4" pos="-0.065 0 0" quat="1 0 0 -3.91037e-08">
                <inertial pos="-0.0399016 -7.71133e-06 0.0114004" quat="0.502878 0.497012 0.497197 0.50288" mass="0.0345308" diaginertia="2.06535e-05 1.77761e-05 5.01407e-06"/>
                <joint name="left_knee" pos="0 0 0" axis="0 0 1" range="-2.0944 2.0944" />
                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
                <body name="foot_module_2" pos="-0.065 0 0" quat="1 0 0 0">
                  <inertial pos="-0.0268732 0.00760284 0.0115562" quat="0.443056 0.532696 -0.463707 0.552189" mass="0.0282341" diaginertia="1.31872e-05 1.21932e-05 5.15725e-06"/>
                  <joint name="left_ankle" pos="0 0 0" axis="0 0 1" range="-1.5708 1.5708" />
                  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
                  <body name="left_foot" pos="-0.0375 0 0.0115" quat="0.5 0.5 0.5 0.5">
                    <inertial pos="0 0 0" mass="1e-09" diaginertia="0 0 0"/>
                  </body>
                </body>
              </body>
            </body>
          </body>
        </body>
        <body name="head_link" pos="0.0306271 -0.0181039 0.0550789" quat="0.707107 -0.707107 0 0">
          <inertial pos="0 -0.0324998 0.0116522" quat="0.707103 0.70711 0 0" mass="0.0208659" diaginertia="1.42995e-05 1.06688e-05 4.80054e-06"/>
          <joint name="neck_pitch" pos="0 0 0" axis="0 0 1" range="-1.309 0.174533" />
          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
          <body name="head_pitch_yaw" pos="0 -0.065 0" quat="0 0.707107 -0.707107 0">
            <inertial pos="0.00984624 -0.00749139 -0.0114146" quat="0.00439214 0.709107 -0.0039939 0.705076" mass="0.0557485" diaginertia="2.05405e-05 1.4997e-05 1.10835e-05"/>
            <joint name="head_pitch" pos="0 0 0" axis="0 0 1" range="-0.698132 0.698132" />
            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
            <body name="head_assembly" pos="0.038 0 -0.0115" quat="0.5 0.5 -0.5 -0.5">
              <inertial pos="-0.00499049 -5.72248e-05 0.0071271" quat="0.00146231 0.713565 -0.00116579 0.700587" mass="0.111822" diaginertia="0.000373616 0.000264094 0.000130946"/>
              <joint name="head_yaw" pos="0 0 0" axis="0 0 1" range="-2.0944 2.0944" />
              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
              <body name="head" pos="0 0 -0.0076" quat="0 1 0 0">
                <inertial pos="0 0 0" mass="1e-09" diaginertia="0 0 0"/>
              </body>
              <body name="left_antenna_assembly" pos="-0.052 -0.0315184 0.0098" quat="0.707107 -0.707107 0 0">
                <inertial pos="-0.00125149 0.0135204 -0.0135694" quat="0.722717 0.676879 0.0872946 -0.109058" mass="0.002174" diaginertia="2.14567e-06 2.0945e-06 1.08402e-07"/>
                <joint name="left_antenna" pos="0 0 0" axis="0 0 1" range="-1.13446 2.0944" />
                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
              </body>
              <body name="right_antenna_assembly" pos="-0.052 0.0315184 0.0098" quat="0.707107 0.707107 0 0">
                <inertial pos="-0.00125149 -0.0135795 -0.0135694" quat="0.676943 0.722645 0.10908 -0.0873716" mass="0.002174" diaginertia="2.16016e-06 2.10899e-06 1.08387e-07"/>
                <joint name="right_antenna" pos="0 0 0" axis="0 0 1" range="-2.0944 1.13446" />
                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
              </body>
            </body>
          </body>
        </body>
      </body>
    </body>
  </worldbody>
  <actuator>
    <position name="right_hip_yaw" joint="right_hip_yaw" inheritrange="1"/>
    <position name="right_hip_roll" joint="right_hip_roll" inheritrange="1"/>
    <position name="right_hip_pitch" joint="right_hip_pitch" inheritrange="1"/>
    <position name="right_knee" joint="right_knee" inheritrange="1"/>
    <position name="right_ankle" joint="right_ankle" inheritrange="1"/>
    <position name="left_hip_yaw" joint="left_hip_yaw" inheritrange="1"/>
    <position name="left_hip_roll" joint="left_hip_roll" inheritrange="1"/>
    <position name="left_hip_pitch" joint="left_hip_pitch" inheritrange="1"/>
    <position name="left_knee" joint="left_knee" inheritrange="1"/>
    <position name="left_ankle" joint="left_ankle" inheritrange="1"/>
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

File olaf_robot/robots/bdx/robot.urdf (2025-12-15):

<robot name="onshape">
    <mujoco>
        <compiler fusestatic="false"/>
    </mujoco>
    <link name="body_module">
        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
        <inertial>
            <origin xyz="-0.00675679511969270747 -0.006637466546945220737 0.0078705246973564610413" rpy="0 0 0"/>
            <mass value="0.50186117579999178773" />
            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
        </inertial>
    </link>
    <link name="trunk">
        <inertial>
            <origin xyz="0 0 0" rpy="0 0 0" />
            <mass value="1e-9" />
            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
        </inertial>
    </link>
    <joint name="trunk_frame" type="fixed">
        <origin xyz="0.032527100485028298538 -0.0066038964305764145252 0.012578922950962011587" rpy="1.5111348801390835856e-14 -6.2433989600656048221e-14 9.1593399531630240418e-16" />
        <parent link="body_module" />
        <child link="trunk" />
        <axis xyz="0 0 0"/>
    </joint>
    <link name="double_u_module">
        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
        <inertial>
            <origin xyz="-0.017000000000027194746 -8.4248510725113835815e-05 0.01158451252812944636" rpy="0 0 0"/>
            <mass value="0.018818301231819770797" />
            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
        </inertial>
    </link>
    <link name="right_hip_pitch_roll_module">
        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
        <inertial>
            <origin xyz="0.011912825164996051694 -0.011752076745460894591 -0.0064503420228230780309" rpy="0 0 0"/>
            <mass value="0.050685765935093662904" />
            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
        </inertial>
    </link>
    <link name="leg_module">
        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
        <inertial>
            <origin xyz="-0.039901628351739881762 -7.7113301695330656099e-06 0.011400440323216621402" rpy="0 0 0"/>
            <mass value="0.034530807353386039349" />
            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
        </inertial>
    </link>
    <link name="leg_module_2">
        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
        <inertial>
            <origin xyz="-0.039901628351740887901 -7.7113301699271358301e-06 0.011400440323216496502" rpy="0 0 0"/>
            <mass value="0.034530807353386039349" />
            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
        </inertial>
    </link>
    <link name="foot_module">
        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
        <inertial>
            <origin xyz="-0.026873167661377921067 0.0076028406460558663887 0.011556240850102265233" rpy="0 0 0"/>
            <mass value="0.028234070013912770242" />
            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
        </inertial>
    </link>
    <link name="right_foot">
        <inertial>
            <origin xyz="0 0 0" rpy="0 0 0" />
            <mass value="1e-9" />
            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
        </inertial>
    </link>
    <joint name="right_foot_frame" type="fixed">
        <origin xyz="-0.037499999999999034106 -6.6570013390609972248e-17 0.011499999999999982458" rpy="1.5707963267948954478 -9.9920072216265019494e-15 1.570796326794896558" />
        <parent link="foot_module" />
        <child link="right_foot" />
        <axis xyz="0 0 0"/>
    </joint>
    <joint name="right_ankle" type="revolute">
        <origin xyz="-0.065000000000002070011 -9.0726037793587011038e-16 1.249000902703301108e-16" rpy="-1.028864493624538396e-14 7.7715611723731079723e-16 2.0438598593485175549e-14" />
        <parent link="leg_module_2" />
        <child link="foot_module" />
        <axis xyz="0 0 1"/>
        <limit effort="1" velocity="20" lower="-1.570796326794896558" upper="1.570796326794896558"/>
        <joint_properties friction="0.0"/>
    </joint>
    <joint name="right_knee" type="revolute">
        <origin xyz="-0.065000000000000890399 -1.8409752888803865289e-16 2.3592239273284576484e-16" rpy="1.1102230529243367767e-16 2.2204460492507932999e-16 -1.1500818382616808057e-13" />
        <parent link="leg_module" />
        <child link="leg_module_2" />
        <axis xyz="0 0 1"/>
        <limit effort="1" velocity="20" lower="-2.0943951023931952626" upper="2.0943951023931952626"/>
        <joint_properties friction="0.0"/>
    </joint>
    <joint name="right_hip_pitch" type="revolute">
        <origin xyz="0.025000000000000646705 -0.024500000000000743405 -0.013499999999999783007" rpy="1.5707963267948972241 -9.4876329561990965088e-14 -3.141592653589793116" />
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

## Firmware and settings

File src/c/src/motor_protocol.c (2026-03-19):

#include "motor_protocol.h"
#include <string.h>

#define PROTOCOL_HEADER 0xFF
#define PROTOCOL_FOOTER 0xFE

int encode_motor_command(const MotorCommand* cmd, uint8_t* buffer, uint16_t* len) {
    if (!cmd || !buffer || !len) return -1;

    buffer[0] = PROTOCOL_HEADER;
    buffer[1] = cmd->id;
    buffer[2] = (cmd->position >> 8) & 0xFF;
    buffer[3] = cmd->position & 0xFF;
    buffer[4] = (cmd->speed >> 8) & 0xFF;
    buffer[5] = cmd->speed & 0xFF;
    buffer[6] = cmd->torque_limit;
    
    uint8_t checksum = 0;
    for (int i = 1; i < 7; i++) {
        checksum += buffer[i];
    }
    buffer[7] = checksum;
    buffer[8] = PROTOCOL_FOOTER;
    
    *len = 9;
    return 0;
}

int decode_motor_status(const uint8_t* buffer, uint16_t len, MotorStatus* status) {
    if (!buffer || !status || len < 9) return -1;
    if (buffer[0] != PROTOCOL_HEADER || buffer[8] != PROTOCOL_FOOTER) return -2;

    uint8_t checksum = 0;
    for (int i = 1; i < 7; i++) {
        checksum += buffer[i];
    }
    if (checksum != buffer[7]) return -3;

    status->id = buffer[1];
    status->current_position = (buffer[2] << 8) | buffer[3];
    status->current_speed = (buffer[4] << 8) | buffer[5];
    status->load = buffer[6]; // Simplified load mapping
    status->temperature = 0; // Temperature not in this packet version

    return 0;
}

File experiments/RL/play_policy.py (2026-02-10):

import argparse
import time
from glob import glob

import gymnasium as gym
import mujoco
import mujoco.viewer
import numpy as np
from gymnasium.envs.registration import register
from stable_baselines3 import PPO, SAC

from olaf_robot.utils.mujoco_utils import check_contact


def get_observation(data, left_contact, right_contact):

    position = (
        data.qpos.flat.copy()
    )  # position/rotation of trunk + position of all joints
    velocity = (
        data.qvel.flat.copy()
    )  # positional/angular velocity of trunk +  of all joints

    obs = np.concatenate(
        [
            position,
            velocity,
            [left_contact, right_contact],
        ]
    )
    # print("OBS SIZE", len(obs))
    return obs


def key_callback(keycode):
    pass


def get_model_from_dir(path_to_model):

    if not path_to_model.endswith(".zip"):
        models_paths = glob(path_to_model + "/*.zip")
        latest_model_id = 0
        latest_model_path = None
        for model_path in models_paths:
            model_id = model_path.split("/")[-1][: -len(".zip")].split("_")[-1]
            if int(model_id) > latest_model_id:
                latest_model_id = int(model_id)
                latest_model_path = model_path

        if latest_model_path is None:
            print("No models found in directory: ", path_to_model)
            return
    else:
        latest_model_path = path_to_model

    return latest_model_path


def get_feet_contact(data, model):
    right_contact = check_contact(data, model, "foot_module", "floor")
    left_contact = check_contact(data, model, "foot_module_2", "floor")
    return right_contact, left_contact


def play(env, path_to_model):
    model_path = get_model_from_dir(path_to_model)

    model = mujoco.MjModel.from_xml_path("../../olaf_robot/robots/Olaf/scene.xml")
    data = mujoco.MjData(model)

    left_contact = False
    right_contact = False

    viewer = mujoco.viewer.launch_passive(model, data, key_callback=key_callback)

    # nn_model = SAC.load(model_path, env)

    nn_model = PPO("MlpPolicy", env)
    nn_model.policy.load(model_path)

    try:
        while True:

            right_contact, left_contact = get_feet_contact(data, model)
            obs = get_observation(
                data,
                left_contact,
                right_contact,
            )
            action, _ = nn_model.predict(obs)
            data.ctrl[:] = action

            mujoco.mj_step(model, data)
            viewer.sync()
            time.sleep(model.opt.timestep / 2.5)

    except KeyboardInterrupt:
        viewer.close()

    viewer.close()


if __name__ == "__main__":

    parser = argparse.ArgumentParser(description="Test model")
    parser.add_argument(
        "-p",
        "--path",
        metavar="path_to_model",
        help="Path to the model. If directory, will use the latest model.",
    )
    parser.add_argument("-a", "--algo", default="SAC")
    args = parser.parse_args()

    register(id="Olaf_env", entry_point="env_humanoid:OlafEnv")
    env = gym.make("Olaf_env", render_mode=None)
    play(env, path_to_model=args.path)

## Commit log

2025-12-15 Initial project scaffold and core structure for Olaf Robotics
    [39281023.prt.stl, antenna.stl, antenna_holder_left.stl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]
2026-01-05 Add initial documentation and assembly guides for Olaf
2026-01-20 Add 3D printable STL files for the Olaf robot chassis
    [Back Panel.3mf, Bambu_X1C_Project_File.3mf, Base_FrontLeft.3mf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]
